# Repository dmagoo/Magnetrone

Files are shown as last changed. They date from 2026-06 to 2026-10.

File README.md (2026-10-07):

# Magnetrone

A motorized MIDI sequencer built around a rotating platter driven by a stepper motor.
Magnets placed on the platter pass over Hall effect sensors to trigger MIDI notes,
turning physical arrangement into musical pattern.

---

## Features

- Rotating platter driven by NEMA17 stepper via GT2 belt drive (11:1)
- 8 analog Hall effect sensors, one per note in the current scale
- MIDI note output on DIN connector
- Teensy Audio Shield output (headphone/line out) with a built-in synth and drum kit
- Voices: Piano, E. Piano, Organ, Synth, Bass, Strings, Brass, Mallets, Reed, Guitar
  and Drums, each with its own wave or harmonics, envelope, note length and filter,
  plus None to mute a layer
- Voice Edit (Aux): live tweaks to a layer's wave, envelope and note length,
  its first 16 harmonics, and its own filter with a filter envelope; Save As keeps them in Custom 1-8 (shared by all
  scenes) or as the current scene's own Scene Voice
- Edit Scale: a Custom scale with one chosen note per track, from Sound
  Defaults or live on the Aux; Save As keeps it in Custom 1-8 (shared by all
  scenes)
- Two magnet layers: a magnet's normal pole plays Layer A, its reversed pole Layer B
  (or both, with Layer B's Mode on Stack, or taking turns by revolution, with
  Layer Turns on Alternate, or each on its own Edit Turns pattern of up to 8
  revolutions),
  each with its own voice, MIDI channel, root note, scale, octave, level, Track
  Shift, Wrap and Low Note (Layer B can follow A's voice, octave, root, scale,
  shift and Low Note one by one, from the menu or the Aux; octave, root and
  scale follow by default)
- Per-layer effects, in a fixed chain: Tone (low-pass Cutoff and Resonance),
  Chorus (Rate, Depth, Mix), Delay (Sync to the beat or Free in ms, up to
  2.4 s, Feedback up to 90%, Mix) and Reverb (Room Size, Damping, Mix). Saved
  in scenes, all off by default; Layer B can follow A's per effect. Tone
  Cutoff, Delay Mix, Delay Feedback and Reverb Mix are also Aux Fns
- Per-layer Track Shift raises the run by scale degrees, with Wrap (the run
  rotates around the arm) or No Wrap (the whole run transposes)
- Per-layer Low Note: Inner or Outer sets which end of the sensor arm plays
  the low end of the run
- Drums play a fixed GM kit (one drum per track, busiest on the outer tracks) on
  MIDI channel 10; Track Shift rotates the kit around the tracks and Low Note
  Outer flips it end to end
- 1 revolution = 1 bar; BPM tracks RPM automatically. Beats/Rev from 1 to 32,
  platter speed from 1 to 120 RPM
- The platter is marked in 16 steps
- Bar start (StartPos): a start mark on the platter, located by calibration or
  re-found later (Auto from one magnet, or Manual by jogging the platter), and
  remembered across power cycles when the platter was at rest
- Front: where the player sits, set first in calibration and Calib. StartPos
  (the magnet is turned to the player, by hand or with the Speed knob, before
  the spin). Tools > Go to Front turns the mark there the shorter way round
- Placement Mode (Tools): Speed jogs the platter (press: Go to Front), Aux snaps
  to the next step or beat, Volume mutes and unmutes single tracks
- Scenes: the whole sound of both layers, 8 saved slots plus a Defaults scene
  edited from the menu; loaded live on the next bar start (or at once, Play
  Setup > Scene Load). Aux changes are live
  only, on top of the current scene. Read-only demo scenes are built into the
  firmware from JSON files (docs/scene-format.md), and a `scenes` serial
  command prints the saved scenes in that format
- Scene Codes (Aux > Scene Codes): a code of up to 14 characters for the
  current sound's main settings (each layer's root, octave, scale, voice,
  shift, Low Note, Wrap and mode, plus Layer Turns and the turn patterns), to enter on another
  table or after a firmware update. Fields at their defaults cost nothing, so
  a code changing only the roots is 3 characters
- [Record Designer](https://dmagoo.github.io/Magnetrone/tools/record-designer/) (`tools/record-designer/`): a
  browser tool to design a "record", a magnet pattern on a step grid plus its
  Scene Code, play it back, save songs and share them as links, and export a
  full-size SVG/PDF template to print or laser cut into a platter cover. Runs
  from the link or straight from disk
- MIDI beat clock driven by platter position, with Song Position Pointer so
  external bars line up with the start mark
- MIDI in (control only): a per-layer input channel; keys drive a MIDI Fn
  (Pitch, Shift, Scale Learn, Set Scale, Fingered or One Finger), the bend wheel bends the table, CC 7 volume,
  CC 20 octave; with Play Setup > MIDI CC on, CCs 74, 71, 93, 94, 12 and 91
  set the effects
- LCD menu: Sound Defaults (both layers), Play Setup, System and Tools
- Speed and volume adjustable live at any time via dedicated encoders; touching
  either one returns to the home screen from any menu (prompts and Scene
  Code entry excepted).
  From a stop, turning Speed starts from zero in the turned direction; a
  press resumes the last speed
- Aux knob changes one bound function live (Pitch, A/B Balance, Layer Turns, Load Scene,
  or a layer's Voice, Root Note, Scale, Octave, Shift, Low Note, Wrap, Mode,
  Tone Cutoff, Delay Mix, Delay Feedback or Reverb Mix); its list also holds
  Save Scene, Scene Codes and Reset All
- Menu knob opens the main menu from the home screen by turning or pressing;
  the Menu button leaves the Aux screens straight back to the home screen, and
  the Aux button leaves the main menu (prompts excepted)
- Welcome tune plays on boot -- previews what Layer A's tracks play, hall 1 to 8
  and back, including its key, octave, Track Shift, Wrap and Low Note; a Menu
  button press skips it
- LCD backlight timeout: configurable from always off to always on
- Stepper motor sleeps when idle to reduce heat and power draw
- Calibration (at 24 RPM, clear platter then one magnet on the start mark)
  measures sensor baselines and noise, threshold, magnet pole, the belt reduction
  (e.g. "Belt 10.9:1", counted in motor steps) and the bar start
- Tools menu: Go to StartPos, Go to Front, Placement Mode, calibration,
  StartPos, Machine Info (RPM, belt ratio, StartPos, threshold, motor driver), live
  Sensor Levels, Sensor Timing, Track Notes and Resources (audio load) screens, Reset Settings (keeps calibration, Front and scenes
  1-8) and Factory Reset
- All settings persisted to EEPROM across power cycles
- Teensy 4.1

---

## Code Summary

The firmware is structured as a set of independent modules: stepper motor control
uses an IntervalTimer ISR for non-blocking step generation; Hall sensor polling
fires each note when the magnet is centered on its sensor, predicted from a
threshold-to-peak angle each sensor learns as it plays (so timing holds on every
track and at any speed), with re-arm and debounce; the sequencer maps sensor
index to scale degree and fires timed MIDI note on/off pairs; the audio module drives
an 8-voice synth bank per magnet layer plus a shared drum kit through the SGTL5000
codec in parallel with MIDI out; the menu
is a simple state machine driven by three encoders with live speed and volume handling
at all times. The platter keeps a signed step count, so the bar phase is exact; MIDI
clock and scene loads are driven from it. A calibration routine samples the sensor
baselines and noise, counts motor steps over one platter revolution, and derives a threshold,
RPM correction factor and bar start stored in EEPROM.

---

## Hardware Summary

The controller is built on a Teensy 4.1 with a Teensy Audio Shield (SGTL5000) for
audio output. A NEMA17 stepper motor drives the platter through a GT2 belt at 11:1
reduction, controlled by a TMC2209 driver (configured over UART) from 24V DC. Eight
ratiometric Hall effect sensors (A1301) are powered at 3.3V and read directly by the
Teensy ADC. A 16x2 I2C LCD with PCF8574T backpack provides the display. MIDI DIN
in/out is present with optoisolation on the input. Power is supplied via 24V barrel
jack through a panel-mount power switch and an MP1584EN buck converter to 5V.

---

## Installation

### Requirements

- PlatformIO (CLI or VS Code extension)
- Teensy 4.1

### Build and Upload

1. Open the `firmware/` directory in VS Code with the PlatformIO extension,
   or use the PlatformIO CLI.

2. Build:

       cd firmware
       pio run -e teensy41

3. Upload:

       pio run -e teensy41 --target upload

### First Run

On first boot, no calibration data is present and the table offers to calibrate
(later: Menu > Tools > Full Calibrate). Clear the platter when asked, then place a
single magnet on the start mark on the outer track. See the
[user guide](docs/user-guide.md) for details.

### Diagnostics

For hardware faults, the firmware has a diagnostics mode used over the USB
serial monitor (`pio device monitor`). Hold the Menu button at power-up, or
type `diag` in the monitor while the table runs. It reports the display, audio
board, motor driver and every sensor every 5 seconds, and takes commands for
running and tuning the motor. Type `help` in the monitor for the commands; see
Troubleshooting > Diagnostics mode in the [user guide](docs/user-guide.md).

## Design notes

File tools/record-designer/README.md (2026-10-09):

# Record Designer

Design a record for Magnetrone: a magnet pattern on a step grid plus the
Scene Code that sets the table up to play it. Exports a full-size template
to laser cut into a platter cover, or to print and place magnets by.

Use it online at https://dmagoo.github.io/Magnetrone/tools/record-designer/, or open `index.html`
in a browser straight from disk (no install, no internet). Work is kept in
the browser's local storage.

Two views, picked at the top right: **Sequence** (grid, playback, scene)
and **Template** (preview and export). The buttons left of them open the
[MIDI](#midi) panel and pick the theme: Auto (follows your system), Light or
Dark.

## Grid

- One row per track, track 1 (inner) at the bottom, track 8 at the top.
  One column per step, step 1 at the left, at the start mark.
- Steps per revolution = Beats/Rev x Subdivisions (default 4 x 4 = 16).
  Changing them keeps every magnet that lands on a step of the new grid.
  Steps are named by beat: 1, 1.2, 1.3, 1.4, 2, ...
- Click an empty slot to place a magnet: A (normal pole, plays Layer A) or
  B (reversed pole, plays Layer B), whichever layer you used last (A at
  first). Click again to flip it to the other layer, again to remove it.
  Clicking a magnet already there flips it, then removes it. Right click
  removes a magnet at once. With the
  colored magnets, A is blue side
  up and B is black side up (the table's calibration sets this; Menu >
  System > Magnet Pole swaps it).
- Block collisions: striped slots would overlap a placed magnet and cannot
  be used; hover one to see which. With it off, overlapping magnets are
  outlined in red. The check uses the larger of the magnet diameter and the
  magnet hole.
- The toolbar counts the magnets placed, in all and per layer.
- Undo and Redo (Ctrl+Z, Ctrl+Y) cover grid edits: slots, Clear and step
  count changes. The history lasts until the page is closed.
- Each magnet shows what it plays with the current scene: a note ("C3"),
  or for drums the letter Track Notes uses (X crash, t low tom, T high tom,
  C clap, O open hat, S snare, K kick, H closed hat). With Stack it shows
  both layers' notes. Each row label shows what an A and a B magnet on
  that track play ("C4/X"), once if they match ("C4"); hovering an empty
  slot shows the same.

## Scene

The Scene Code fields, grouped as Sound (voice, root, octave, scale, each
with a Same as A box for Layer B; Octave, Root and Scale on by default),
Arrangement (shift, Low Note, Wrap, Layer B's Same as A settings) and
Layers (modes, Layer Turns, Edit Turns). Settings that have no effect right now (a Drums
layer's root, a layer that is Off, Layer B on Same as A) are greyed out but
stay editable, since the code still holds them; hover one to see why.
Hover a setting's name (dotted underline) for what it does. Each Shift
option shows what the low track then plays ("1  D4", or "5  Snare" on
Drums); Low Note's options say which track is low (Inner, track 1; Outer,
track 8). Octave is a number box, 0 to 7.

**Scale** includes **Custom**: one note per track, as on the table. The
**Edit Scale** row lists each layer's eight slots as the table's Edit Scale
does ("C+0" is the C in the layer's Octave, "C+1" the one above; slot 1 is
the low track at Shift 0), the Custom notes or, until the layer plays a
Custom scale, its scale's first eight notes. Changing a slot makes the scale
Custom, starting from what it was playing; choosing Custom with none set
does the same. **Reset** puts the layer's Scale and Custom notes back to the
song as saved (the factory scene for a song not saved yet). Layer B following
A's Scale plays A's Custom notes.

The Scene Code does not hold a Custom scale (it reads as Major on the
table), so a Custom scale is kept in the song and its link, not the code.
The Scene panel and the Template view say so whenever a layer plays one, and
the template's labels list its notes, to set on the table with Edit Scale.

**Hear: A / B** (Scene header) plays that layer's tracks 1 to 8 up and
back down in sixteenths, as the table plays its welcome tune at power-up
(the table's tune is Layer A). With **Auto** on, changing a scene setting
plays the changed layer's run, unless the grid is playing.

Beside it, the swap button (two arrows) swaps Layers A and B, and **A→B**
copies Layer A to Layer B, leaving A as it is. Both cover the settings the
two layers share: Voice, Root, Octave, Scale, Shift, Low Note, Wrap and the
turn patterns. Mode, Layer B's Same as A boxes and Layer Turns stay as they
are.

**Edit Turns** shows each layer's turns as the table does: a turn's number
if the layer's magnets are heard on that revolution, - if not, | where the
cycle ends (8 turns without one). Click a turn to change it: on, off, the
end of the cycle (not turn 1), on again. Clicking the | or past it makes the
cycle 8 turns again. Changing a turn sets Layer Turns to Custom, starting
from what it was playing; Together and Alternate keep the Custom patterns.
The turn the position is on is shaded in each layer's strip.

**Reset Scene**, under the settings, sets every scene setting to the factory
values, as with nothing saved (asks first). The grid, BPM and template
settings stay.

The code shows beside Play, with a copy button, and updates as you change
the settings. It is up to 10 characters, or 14 with Layer Turns on Custom or
a voice from E. Piano on. A code can be loaded back. Enter the
code on the table under Aux > Scene Codes > Enter. Beats/Rev is not in the
code; set it on the table under Menu > Play Setup > Beats/Rev.

## Play

Plays the grid at the BPM given, with the table's note mapping (scale
degree, Shift, Wrap, Low Note, Same as A, Stack, Off, Layer Turns, the drum
kit). The RPM that BPM means on the table is shown beside it; BPM is kept
within the table's 1 to 120 RPM at the current Beats/Rev. The sounds are
approximations of the table's voices. Turn 1 of Layer Turns is the first
revolution, and beside BPM the layers heard on the current revolution are
shown ("Turn: A + B") unless Layer Turns is Together.

- Play / Pause (Space). Pause keeps the position; Play goes on from there.
- To start (Home) moves the position back to step 1.
- The arrows button (right of Play) plays backwards, as the table does with
  Speed turned below zero. Playing, it turns round at the current step.
- Click a step number to move the position there. Paused, that column
  plays once; playing, it jumps there.
- Placing a magnet plays its note.
- The shaded band shows the position.

## MIDI

The MIDI button (left of the theme button) opens the MIDI panel. It works in
Chrome and Edge, through the browser's Web MIDI; Safari has none. **Use
MIDI** turns it on (the browser asks for access the first time). The
settings are kept per browser, like the table's Play Setup, not in the song.
The button lights while MIDI is on and blinks when a message comes in.

MIDI In works as the table's MIDI IN (see the user guide's MIDI In section):

- **MIDI In**: All inputs, None, or one port. **A In channel** and **B In
  channel** (default 1 and 2, or Off) are the channels each layer listens on;
  both on one channel apply to both. Layer B on Same as A does not listen.
- **MIDI Fn**: what keys do. Off, Pitch, Set Scale, Fingered, One Finger,
  Shift, Play Along, Scale Learn, as on the table. Changing it releases held
  keys. Fingered, One Finger and Scale Learn write the layer's Custom scale
  (see [Scene](#scene)).
- Scene changes from MIDI (keys, CC 20 Octave) edit the song: the chip shows
  "(edited)", **Save** keeps them and **Revert** drops them, as Save Scene
  keeps them on the table.
- Play Along keys play the layer's voice, velocity counting, as long as
  held. On a drum layer each drum plays on its General MIDI key.
- The bend wheel bends everything up to 2 semitones, notes sounding
  included. **CC 7** sets the volume. With **MIDI CC** on, CCs 74, 71, 93,
  94, 12 and 91 set each layer's Tone Cutoff and Resonance, Chorus Mix,
  Delay Mix and Feedback, and Reverb Mix.

Volume, bend and effects are live only: not saved with the song (the Scene
Code does not hold them either). The panel shows them under **Live, not
saved**, with a button to reset them. They start as the table's factory
settings (volume 50%, effects off; Delay Sync 1/2 beat, Feedback 30%). The
effects are approximations of the table's.

MIDI Out, while the grid plays:

- Each layer's notes on its voice's Auto channel (Piano 1, Bass 2,
  Strings 3, Synth 4, E. Piano 5, Organ 6, Brass 7, Mallets 8, Reed 9,
  Drums 10, Guitar 11), velocity 127, for the voice's note length (drums
  50 ms). A track's next note ends the one before.
- The bend, on the melodic channels in use, each told the bend range first.
- Clock (24 a beat) with Song Position and Continue on Play, and Stop on
  Pause. A jump, turning round or a Beats/Rev change starts the clock over.
- Hear runs, placed magnets and Play Along keys are not sent out.

Not here, as on the table: following an external clock.

## Songs and sharing

The **Songs** strip under the transport keeps saved songs as chips, in
this browser's local storage. On a narrow screen (under 600 px) the chips
wrap onto as many rows as they need, with the buttons below them.

- **Save** keeps your changes in the chip you are on (it is greyed when
  there is nothing to save). A song not saved yet (new, or started from
  Empty) is named first and becomes a chip. Until you save, the chip shows
  "(edited)".
- **Save as new** makes a new chip and leaves the one you are on as it was.
  The name is pre-filled with a copy number, "My tune (2)"; only a
  trailing "(n)" counts up, so "Waltz no. 3" becomes "Waltz no. 3 (2)".
- **Revert** discards your edits and goes back to the saved chip (asks
  first; greyed when there is nothing to revert). Clicking the edited chip
  does the same.
- Click a chip to switch to it. Playing carries on into the new song. If
  the current song has unsaved changes, it asks first.
- Double-click a chip to rename it; x removes it. **Empty** is always
  there: the factory scene on an empty grid.
- The link button beside the Scene Code copies a link holding the whole
  song and its name: grid, scene (Custom scales included), BPM and template
  settings. It asks for a
  name if the song has none, and saves the song as Save does.
- Opening a link adds its song as a chip (or picks the chip it already is),
  so you can always get back to it. It points at this page's address, so
  it opens the song for anyone who has the page there, such as the hosted
  copy; a link to a file on your drive only works on your machine.

## Template

SVG or PDF, full size, on Letter or A4. If printing, print at 100% (actual
size, no fit to page) and check the 100 mm scale bar.

| Color | Lines |
|---|---|
| Red `#FF0000` | Through cut: outline (200 mm) and center hole (14 mm) |
| Green `#00FF00` | Layer A magnet holes (default 11 mm, for 10 mm magnets): cut through or kiss cut |
| Magenta `#FF00FF` | Layer B magnet holes, same size |
| Blue `#0000FF` | Score: track rings, start mark, the A/B mark beside each hole, Scene Code and Beats/Rev, song name |
| Black | Labels and scale bar, below the record. Not part of the record. Template settings **Labels below the record** (default on, kept per browser) leaves them out of the export. |

All lines are hairlines (0.001 in). The start mark is at the top.

- Track rings are broken around every hole, with a gap 1 mm wider than the
  hole, so they never cross one. A ring with no holes is a whole circle.
- The A/B mark sits just after its hole, in step order; just before it if a
  magnet is packed right after; left off if magnets are packed on both
  sides.
- The Scene Code and Beats/Rev ("J  4 BEATS/REV") are 5 mm tall along a
  track ring, centered in the longest stretch with no magnets, outer tracks
  first; the ring is broken under them. Without room at 5 mm they are 3 mm;
  without room at 3 mm they fall back to 1.5 mm along the outer edge, and
  the Template view says so. Leaving a few steps in a row free on one track
  (outer tracks need the fewest) keeps them readable.
- **Platter marks** (Template settings: Off, 10, 12 or 16, default 16): 5 mm ticks
  across every ring, evenly spaced from the start mark, like the marks on a
  platter cover, so the template can be used as a guide on a marked cover
  without cutting it. They are the cover's, not the song's: they ignore
  Beats/Rev and the steps, are kept per browser, and are not in the song
  or its link. A tick near a hole (or its A/B mark) or across text on its
  ring is left out.
- A saved song's name is scored the same way, after the code, in the
  longest stretch left clear of magnets and the code. Without room on a
  ring it takes the outer edge, unless the code is already there; then it
  is left off the record. The Template view says so either way. It is also
  the first label below the record, when labels are on. Letters the template font lacks are
  dropped.

- A layer playing a Custom scale gets a label line with its Edit Scale
  notes ("A EDIT SCALE (NOT IN CODE): 1:C+0 2:D+0 ..."), since the code
  does not hold them. With labels off they are not on the export, and the
  Template view says so.

Lay the template on the platter with the center hole on the spindle and
the start mark on the platter's start mark.

## Platter direction

- **Platter forward, seen from above** (Template settings): Clockwise,
  confirmed on the table 2026-10-04. Steps run around the template in the
  order they pass the sensor arm, so this must match the table or the
  record plays backwards.

## Sources

- Track radii and magnet diameter: `firmware/include/config.h`
  (`TRACK_RADIUS_MM`, `MAGNET_DIAMETER_MM`), which match the platter CAD.
- Outline and center hole: `hardware/cad/platter/dxf/Platter - Disc.dxf`.
- Scene Code: a port of `firmware/src/sequencer/scene_code.cpp`.
- MIDI: `firmware/src/midi/midi_in.cpp`, `midi.cpp`, `transport.cpp`;
  effects: `audio/audio.cpp`, `config/storage.cpp` (factory effects).
- Note mapping: `firmware/src/sequencer/layers.cpp`, `sequencer.cpp`,
  `scale.cpp`, `audio/kit.h`, `audio/voice.cpp`.

If any of these change in the firmware, change them here too.

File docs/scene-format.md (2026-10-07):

# Scene Format

A scene written as JSON. It is the source format for the demo scenes built into
the firmware (the demos at the end of the **Load Scene** list), and what the table prints when it dumps
its saved scenes over USB serial. It is meant for whoever makes demos, and is
the implementation guide for the feature, not for playing the table: see the
[User Guide](user-guide.md) for that.

To share a sound by hand instead, without a computer, use a Scene Code (see
[Scene Codes](user-guide.md#scene-codes) in the User Guide). A code holds only
each layer's main settings, not effects, levels or custom voices.

## Rules

- **Leave out what you did not change.** Any field left out takes its factory
  value, the same one Factory Reset gives. So a demo lists only what makes it
  different, and if the factory values change, demos that leave a field out
  follow. This applies everywhere, harmonics included. The scene that is loaded
  is always complete.
- **Names, not numbers.** Settings such as voice, scale or root are written by
  name. Names are not case sensitive; this document writes them in lowerCamel
  (`drums`, `off`, `pentatonicMinor`). An unknown name fails the build.
- **Keys are lowerCamel** (`lowNote`, `shiftSameAsA`).
- **The dump leaves out factory values** for you, so a dumped scene already
  holds only its changes. Prune further by hand.
- **Demos must not use Custom 1 to 8.** Those are edited by the player, so a
  demo would change under them. Use a scene voice (`sceneVoice`) instead, or
  for a scale, the layer's own `custom`.

## Scene

| Key | Value |
|-----|---|
| `name` | The scene's name. |
| `pitch` | Pitch offset in semitones; fractions allowed. Factory 0. |
| `balance` | A/B Balance, -10 (all A) to 10 (all B). Factory 0. |
| `layerA`, `layerB` | The two layers, below. |
| `customVoices` | Dump only, printed on its own after the scenes: Custom 1 to 8 (`custom1` ... `custom8`), each a voice as below. They are shared by every scene, not part of one, so a demo cannot have this. |
| `customScales` | Dump only, like `customVoices`: the saved Custom scales 1 to 8 (`custom1` ... `custom8`), each a list of steps as `custom` below. |

## Layer

| Key | Value |
|-----|---|
| `mode` | `on`, `off`. Layer B also: `sameAsA`, `stack`. |
| `voice` | `piano`, `ePiano`, `organ`, `synth`, `bass`, `strings`, `brass`, `mallets`, `reed`, `guitar`, `drums`, `none`, `custom1` to `custom8`, or `sceneVoice`. (`synth` was `leads` before 2026-10-06.) |
| `sceneVoice` | The layer's own voice, a voice as below. Used when `voice` is `sceneVoice`. |
| `channel` | `auto` (follows the voice), or a MIDI channel 1 to 16. |
| `root` | `c`, `c#`, `d`, `d#`, `e`, `f`, `f#`, `g`, `g#`, `a`, `a#`, `b`. |
| `scale` | `major`, `minor`, `pentatonicMajor`, `pentatonicMinor`, `blues`, `chromatic`, `dorian`, `mixolydian`, `learned`, `custom`. |
| `learned` | The Learned scale: semitones above the root, 0 to 11. Empty if none (then `learned` plays as major). |
| `custom` | The Custom scale (Edit Scale): one note per track, slot 1 first, as 8 steps in semitones from the root, -12 to 35 (12 is the octave above). Left out if none (then `custom` plays as major). |
| `octave` | 0 to 7. |
| `level` | 0 to 100 (percent). |
| `shift` | Track Shift, 0 to 7. |
| `wrap` | `true` or `false`. |
| `shiftSameAsA` | Layer B only: play A's Shift and Wrap. |
| `lowNote` | `inner` or `outer`. |
| `lowNoteSameAsA` | Layer B only: play A's Low Note. |
| `rootSameAsA` | Layer B only: play A's Root. Factory `true`, so a Layer B that sets its own `root` also sets this `false`. |
| `scaleSameAsA` | Layer B only: play A's Scale (with A's `learned` and `custom`). Factory `true`, as `rootSameAsA`. |
| `voiceSameAsA` | Layer B only: play A's Voice. Factory `false`. |
| `octaveSameAsA` | Layer B only: play A's Octave. Factory `true`, so a Layer B that sets its own `octave` also sets this `false`. |
| `turns` | Layer B only: Layer Turns, `together`, `alternate` or `custom`. |
| `turnPattern` | The layer's turns (Edit Turns), played while Layer B's `turns` is `custom`: as the table shows them, turn n's number if the layer plays it, `-` if not, then `\|` where the cycle ends if it is shorter than 8, such as `"1-3-5-7-"` or `"1--\|"`. Factory `"12345678"`. |
| `tone`, `chorus`, `delay`, `reverb` | The layer's effects, below. |

## Effects

Percentages run 0 to 100. On Layer B, each effect also takes `sameAsA`
(`true` plays A's settings for that effect).

| Effect | Keys |
|---|---|
| `tone` | `cutoff` (`off` = 100), `resonance`. |
| `chorus` | `rate`, `depth`, `mix` (`off` = 0). |
| `delay` | `mode` (`sync` or `free`), `sync` (`1`, `1/2`, `3/8`, `1/3`, `1/4`, `1/5`, `1/6`, `3/16`, `1/8`, `1/10`, `1/12`, `1/16`, `1/32` of a beat), `time` (free time, 10 to 2400 ms), `feedback` (0 to 90), `mix` (`off` = 0). |
| `reverb` | `roomSize`, `damping`, `mix` (`off` = 0). |

## Voice

Used by `sceneVoice` and `customVoices`.

| Key | Value |
|-----|---|
| `base` | The built-in voice it was made from (any `voice` name above but `none`, and not a custom or scene voice); sets the Auto MIDI channel and every field left out. |
| `wave` | `sine`, `triangle`, `saw`, `square`. |
| `harmonics` | Up to 16 levels, 0 to 100, from the fundamental up. Present means the voice plays these instead of the stock wave. Left out, it plays what `base` plays: its harmonics if it has them (most built-ins do), else its wave, or `wave` if given. A shorter list takes the rest from the stock wave (of `wave`, or of `base`). |
| `attack`, `decay`, `release` | Milliseconds. |
| `sustain` | 0 to 100 (percent). |
| `length` | Note length, milliseconds. |
| `filter` | The voice filter: `cutoff` (`off` = 100), `resonance`, `amount`, `attack`, `decay`, `release` (milliseconds), `sustain` (percent). |

## Dumping scenes from the table

1. Save the scene you dialed in to a slot (**Aux > Save Scene**).
2. Switch the table off and unplug the 24V supply. Never connect USB while
   the 24V supply is plugged in.
3. Connect USB and open a serial monitor.
4. Type `scenes`. The table prints Defaults and every used scene 1 to 8, each
   under a `--- Scene 3 ---` line, then the used Custom voices, as JSON. It
   leaves out fields that match the factory values, and in a voice, those that
   match its `base`.
5. Copy the scene you want, from `{` to `}`, into a demo file (below). Set its
   `name` and prune it by hand. A scene playing a Custom voice has to be
   changed to a `sceneVoice` first (copy the voice from the Custom voices).

## Adding a demo

1. Add a file to `firmware/demos/`, one demo per file. The file name sets the
   of the demos in **Load Scene**, so start it with a number:
   `01-drift.json`, `02-undertow.json`.
2. Set `name`: that is what the Load Scene list shows.
3. Build. A script runs before every build, checks each demo and turns them
   into firmware data. A bad file (unknown key or name, value out of range,
   a Custom voice) fails the build with the file and the field. To check the
   files without building, run `python tools/build_demos.py` in `firmware/`.
4. Flash, and load it from **Aux > Load Scene**: the demos follow scene 8, as
   `Demo1: Drift` (the name cut to fit the display).

## Implementation

- **Dump:** the `scenes` serial command in normal mode
  (`src/sequencer/scene_dump.cpp`, called from the serial poll that also
  listens for `diag`). It compares against `storageFactoryScene()` and, for a
  voice, `storageStockVoice(base)`.
- **Build:** `tools/build_demos.py`, run by PlatformIO before each build
  (`extra_scripts = pre:...`). It reads `demos/*.json` in file name order,
  validates them, and writes `src/sequencer/demos_data.h` (generated, not in
  git). Names are matched case insensitively.
- **Factory fill:** the generated data holds only the fields each demo sets.
  The firmware builds a demo by starting from `storageFactoryScene()` and
  applying them (`src/sequencer/demos.cpp`), so a change to the factory values
  reaches every demo that leaves that field out.
- **Storage:** demos live in flash, read-only, and take none of the 8 slots.
  Their scene ids follow the slots (Demo 1 is id 9). The current scene id is
  saved as for a slot, so a demo loads again at power-up; if a later build has
  fewer demos, Defaults loads instead. Adding or reordering demo files shifts
  which demo an id names.
- **Menu:** the demos follow scene 8 in the **Load Scene** list and load like
  any scene, at the next bar. The home screen shows `Demo 1`. The `*` mark and
  Aux **Reset All** compare against the demo.
- **Scene voices:** every scene load, saved or demo, copies the scene's own
  voices into the live sound, and a layer set to Scene Voice plays that copy.
- **Saving:** **Save Scene** to a slot saves a loaded demo like any scene, its
  voices included. **Voice Edit > Save As** offers no Scene Voice in a demo,
  as in Defaults: save the scene to a slot first.

## Example

The factory Defaults scene with every field written out, except that Layer A
plays Piano as a scene voice, plus a Custom 1 as a dump would show it. A demo
would leave out everything here that matches the factory values.

```json
{
  "name": "defaults",
  "pitch": 0.0,
  "balance": 0,
  "layerA": {
    "mode": "on",
    "voice": "sceneVoice",
    "sceneVoice": {
      "base": "piano",
      "wave": "triangle",
      "attack": 5,
      "decay": 400,
      "sustain": 20,
      "release": 400,
      "length": 250,
      "filter": {
        "cutoff": "off",
        "resonance": 0,
        "amount": 0,
        "attack": 5,
        "decay": 300,
        "sustain": 50,
        "release": 300
      }
    },
    "channel": "auto",
    "root": "c",
    "scale": "major",
    "learned": [],
    "octave": 4,
    "level": 100,
    "shift": 0,
    "wrap": false,
    "lowNote": "inner",
    "tone":   { "cutoff": "off", "resonance": 0 },
    "chorus": { "rate": 30, "depth": 50, "mix": "off" },
    "delay":  { "mode": "sync", "sync": "1/2", "time": 300, "feedback": 30, "mix": "off" },
    "reverb": { "roomSize": 50, "damping": 50, "mix": "off" }
  },
  "layerB": {
    "mode": "on",
    "voice": "drums",
    "channel": "auto",
    "voiceSameAsA": false,
    "octaveSameAsA": true,
    "rootSameAsA": true,
    "root": "c",
    "scaleSameAsA": true,
    "scale": "major",
    "learned": [],
    "octave": 3,
    "level": 100,
    "shift": 0,
    "wrap": false,
    "shiftSameAsA": false,
    "lowNote": "inner",
    "lowNoteSameAsA": false,
    "turns": "together",
    "tone":   { "sameAsA": false, "cutoff": "off", "resonance": 0 },
    "chorus": { "sameAsA": false, "rate": 30, "depth": 50, "mix": "off" },
    "delay":  { "sameAsA": false, "mode": "sync", "sync": "1/2", "time": 300, "feedback": 30, "mix": "off" },
    "reverb": { "sameAsA": false, "roomSize": 50, "damping": 50, "mix": "off" }
  },
  "customVoices": {
    "custom1": {
      "base": "strings",
      "wave": "saw",
      "harmonics": [100, 50, 33, 25, 20, 17, 14, 12, 11, 10, 9, 8, 8, 7, 7, 6],
      "attack": 150,
      "decay": 100,
      "sustain": 80,
      "release": 600,
      "length": 800,
      "filter": {
        "cutoff": 60,
        "resonance": 20,
        "amount": 40,
        "attack": 10,
        "decay": 300,
        "sustain": 50,
        "release": 300
      }
    }
  }
}
```

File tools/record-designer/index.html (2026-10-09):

# Magnetrone Record Designer

## MIDI

Use MIDI (Chrome or Edge)

MIDI In MIDI Out A In channel B In channel MIDI Fn MIDI CC

In: keys drive the MIDI Fn, the bend wheel bends, CC 7 sets the volume and CC 20 the octave. Scene changes edit the song (Save keeps them). Out: each layer's notes on its voice's Auto channel, the bend, and clock with Start and Stop while the grid plays.

### Live, not saved

Reset volume, bend and effects

BPM

Scene Code

Songs:

Save Save as new Revert

Beats/Rev x Subdivisions

Block collisions

Clear

Click an empty slot to place a magnet on the layer you used last (A, normal pole, or B, reversed pole); click again to flip it, again to remove it. Track 1, the inner track, is the bottom row. Step 1 is the start mark. Striped slots would overlap a placed magnet.

## Scene

Hear: A B Auto

A→B

Load

### Sound

### Arrangement

### Layers

Reset Scene

## Template

A 200 mm record, full size, for laser cutting or printing.

No track has room for a readable Scene Code, so it is only 1.5 mm tall at the edge. Leave a few steps in a row free on one track (outer tracks need the fewest).

Paper Magnet hole (mm) Platter forward, seen from above Check this on the table: steps are placed in the order they pass the sensor arm. Platter marks Ticks across every ring, evenly spaced from the start mark, as on a platter cover. They ignore the song's steps. Labels below the record The black text and 100 mm bar. Off, the export has only the record's lines.

Export PDF Export SVG

If printing, print at 100% (actual size, not fit to page) and check the 100 mm bar.

### Line colors

- Cut: outline and center hole
- Layer A magnet holes
- Layer B magnet holes
- Score: rings, start mark, marks, code
- Labels, not part of the record (optional)

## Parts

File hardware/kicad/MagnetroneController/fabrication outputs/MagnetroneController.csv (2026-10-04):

Reference | Qty | Value | DNP | Exclude from BOM | Exclude from Board | Footprint | Datasheet
C1,C2 | 2 | 100uf |  |  |  | Capacitor_THT:CP_Radial_D8.0mm_P3.80mm | ~
C9 | 1 | .1uf |  |  |  | Capacitor_SMD:C_0805_2012Metric_Pad1.18x1.45mm_HandSolder | ~
D1 | 1 | D |  |  |  | Diode_SMD:D_SOD-123 | ~
D2 | 1 | SS34 |  |  |  | Diode_SMD:D_SMA | https://www.vishay.com/docs/88751/ss32.pdf
F1 | 1 | Polyfuse |  |  |  | Fuse:Fuse_Bourns_MF-RHT300 | ~
H1,H2,H3,H4 | 4 | MountingHole_Pad |  | Excluded from BOM |  | MountingHole:MountingHole_3.2mm_M3_ISO7380_Pad_TopBottom | ~
J1 | 1 | Conn_01x04 |  |  |  | Connector_PinHeader_2.54mm:PinHeader_1x04_P2.54mm_Vertical | ~
J2,J3 | 2 | DIN-5_180degree |  |  |  | music-table-footprints:MIDI_Wire_245 | http://www.mouser.com/ds/2/18/40_c091_abd_e-75918.pdf
J4 | 1 | Barrel_Jack_MountingPin |  |  |  | Connector_BarrelJack:BarrelJack_CUI_PJ-102AH_Horizontal | ~
J7 | 1 | Conn_02x05_Odd_Even |  |  |  | Connector_IDC:IDC-Header_2x05_P2.54mm_Vertical | ~
J8 | 1 | Conn_02x13_Counter_Clockwise |  |  |  | Connector_IDC:IDC-Header_2x13_P2.54mm_Vertical | ~
R1 | 1 | 10 |  |  |  | Resistor_SMD:R_0805_2012Metric_Pad1.20x1.40mm_HandSolder | ~
R2 | 1 | 33 |  |  |  | Resistor_SMD:R_0805_2012Metric_Pad1.20x1.40mm_HandSolder | ~
R3 | 1 | 220 |  |  |  | Resistor_SMD:R_0805_2012Metric_Pad1.20x1.40mm_HandSolder | ~
R4 | 1 | 470 |  |  |  | Resistor_SMD:R_0805_2012Metric_Pad1.20x1.40mm_HandSolder | ~
R5 | 1 | 1k |  |  |  | Resistor_SMD:R_0805_2012Metric_Pad1.20x1.40mm_HandSolder | ~
SW9 | 1 | SW_SPST 24V |  |  |  | Connector_JST:JST_XH_B2B-XH-AM_1x02_P2.50mm_Vertical | ~
U1 | 1 | TMC2209_BTT_V1.3 |  |  |  | magnetrone:TMC2209_BTT_V1.3 | https://global.bttwiki.com/TMC2209.html
U9 | 1 | ~ |  |  |  | MP1584EN:SRT_MPT1584EN_Module
U10 | 1 | Teensy4.1 |  |  |  | magnetrone:Teensy41_AudioShield_RevD
U12 | 1 | 6N137 |  |  |  | Package_DIP:DIP-8_W7.62mm | https://docs.broadcom.com/docs/AV02-0940EN

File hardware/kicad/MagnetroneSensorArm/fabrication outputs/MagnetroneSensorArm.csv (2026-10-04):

Reference | Qty | Value | DNP | Exclude from BOM | Exclude from Board | Footprint | Datasheet
C1,C2,C3,C4,C5,C6,C7,C8 | 8 | .1uf |  |  |  | Capacitor_SMD:C_0805_2012Metric_Pad1.18x1.45mm_HandSolder | ~
H1 | 1 | MountingHole_Pad |  | Excluded from BOM |  | MountingHole:MountingHole_3.2mm_M3_ISO7380_Pad_TopBottom | ~
J1 | 1 | Conn_02x05_Odd_Even |  |  |  | Connector_IDC:IDC-Header_2x05_P2.54mm_Vertical | ~
R1,R3,R5,R7,R9,R11,R13,R15 | 8 | 15k |  |  |  | Resistor_SMD:R_0805_2012Metric_Pad1.20x1.40mm_HandSolder | ~
R2,R4,R6,R8,R10,R12,R14,R16 | 8 | 7.5k |  |  |  | Resistor_SMD:R_0805_2012Metric_Pad1.20x1.40mm_HandSolder | ~
U1,U2,U3,U4,U5,U6,U7,U8 | 8 | A1301KLHLT-T |  |  |  | Package_TO_SOT_SMD:SOT-23W | http://www.allegromicro.com/~/media/Files/Datasheets/A1301-2-Datasheet.ashx

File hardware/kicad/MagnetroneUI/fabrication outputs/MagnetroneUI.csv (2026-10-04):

Reference | Qty | Value | DNP | Exclude from BOM | Exclude from Board | Footprint | Datasheet
H1,H2,H3,H4 | 4 | MountingHole_Pad |  | Excluded from BOM |  | MountingHole:MountingHole_3.2mm_M3_ISO7380_Pad_TopBottom | ~
J1 | 1 | Conn_01x04 |  |  |  | Connector_PinHeader_2.54mm:PinHeader_1x04_P2.54mm_Vertical | ~
J2 | 1 | Conn_02x13_Counter_Clockwise |  |  |  | Connector_IDC:IDC-Header_2x13_P2.54mm_Horizontal | ~
Q1,Q2 | 2 | BSS138 |  |  |  | Package_TO_SOT_SMD:SOT-23 | https://www.onsemi.com/pub/Collateral/BSS138-D.PDF
R1,R2,R3,R4,R5,R6,R7,R8,R11,R13 | 10 | 10k |  |  |  | Resistor_SMD:R_0805_2012Metric_Pad1.20x1.40mm_HandSolder | ~
R12,R14 | 2 | 10k | DNP |  |  | "Resistor_SMD:R_0805_2012Metric_Pad1.20x1.40mm_HandSolder" | ~
SW1 | 1 | SW_Push |  |  |  | TerminalBlock_Phoenix:TerminalBlock_Phoenix_MKDS-1,5-2_1x02_P5.00mm_Horizontal | ~
SW2,SW3,SW4,SW5 | 4 | RotaryEncoder_Switch_MP |  |  |  | Rotary_Encoder:RotaryEncoder_Alps_EC11E-Switch_Vertical_H20mm | ~

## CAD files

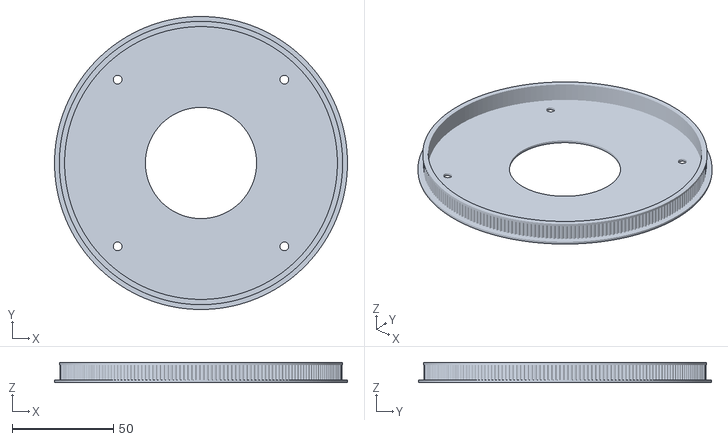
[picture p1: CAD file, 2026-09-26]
hardware/cad/base/stl/Gear Mount - PulleyMount.stl
145.0 x 145.0 x 10.0

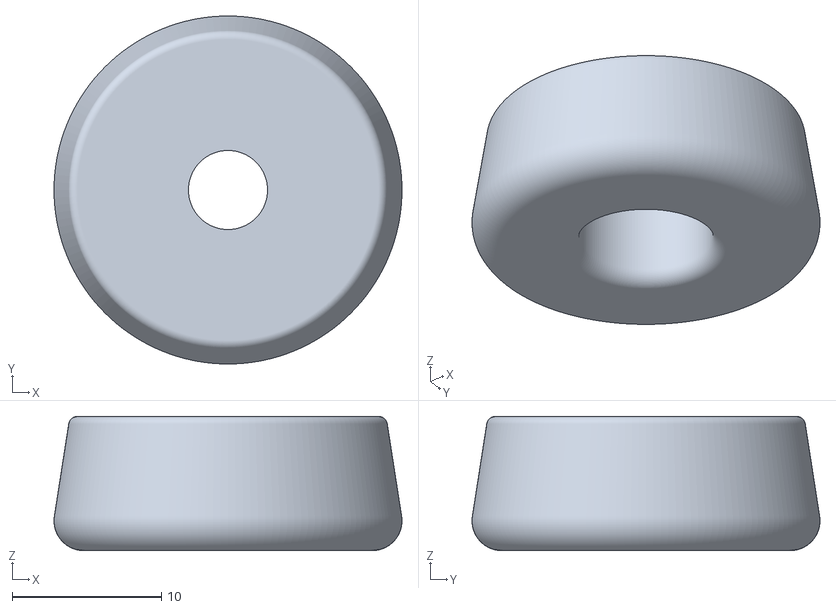
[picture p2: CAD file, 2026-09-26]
hardware/cad/frame/stl/Frame - M5 Foot.stl
23.3 x 23.3 x 9.00

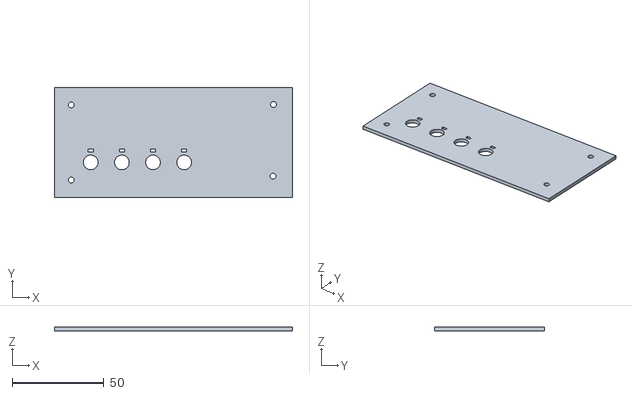
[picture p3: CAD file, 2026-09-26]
hardware/cad/panels/stl/UI Panel - Encoder Panel.stl
130.0 x 60.0 x 2.00

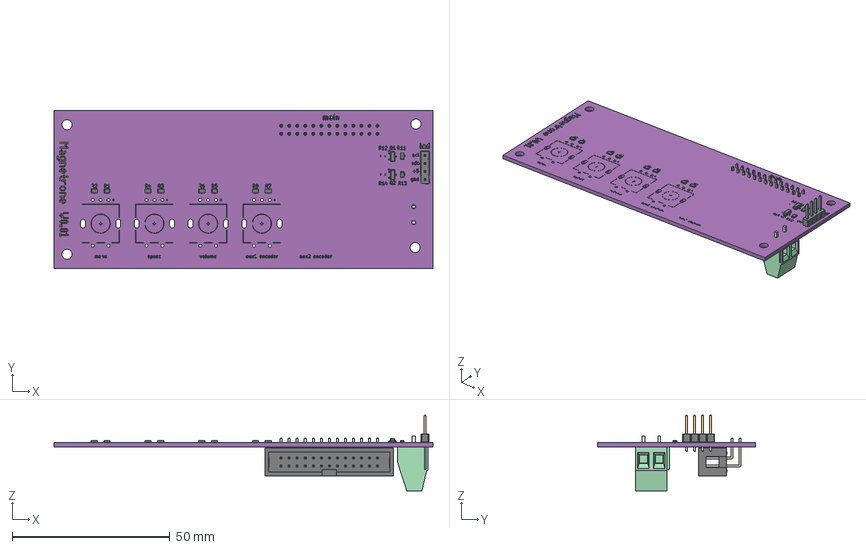
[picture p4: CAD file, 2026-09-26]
hardware/cad/pcb/MagnetroneUI.step
120.0 x 50.0 x 24.0 mm
R_0805_2012Metric x 10
SOT-23 x 2
PinHeader_1x04_P2.54mm_Vertical
IDC-Header_2x13_P2.54mm_Horizontal
TerminalBlock_Phoenix_MKDS-1,5-2_1x02_P5.00mm_Horizontal
MagnetroneUI_silkscreen
MagnetroneUI_PCB

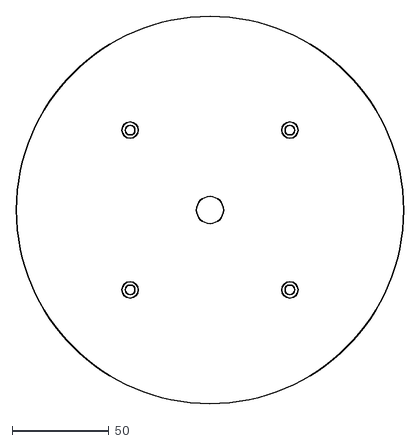
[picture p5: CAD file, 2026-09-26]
hardware/cad/platter/dxf/Platter - Disc.dxf
200.0 x 200.0

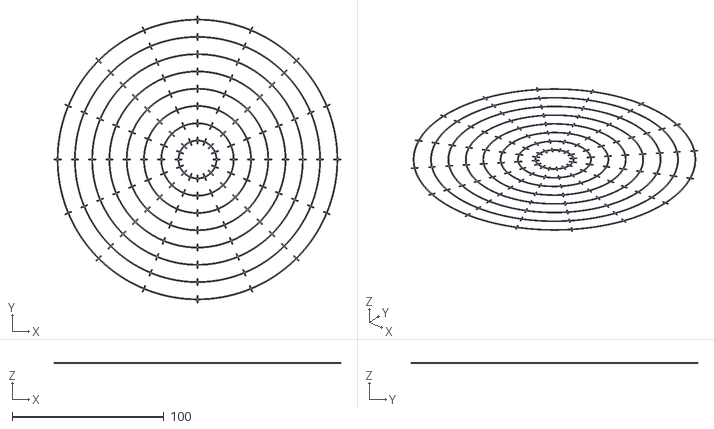
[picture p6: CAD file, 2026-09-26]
hardware/cad/platter/stl/Music Table - Platter - Cover - NEGATIVE LINES.stl
189.4 x 189.4 x 0.2

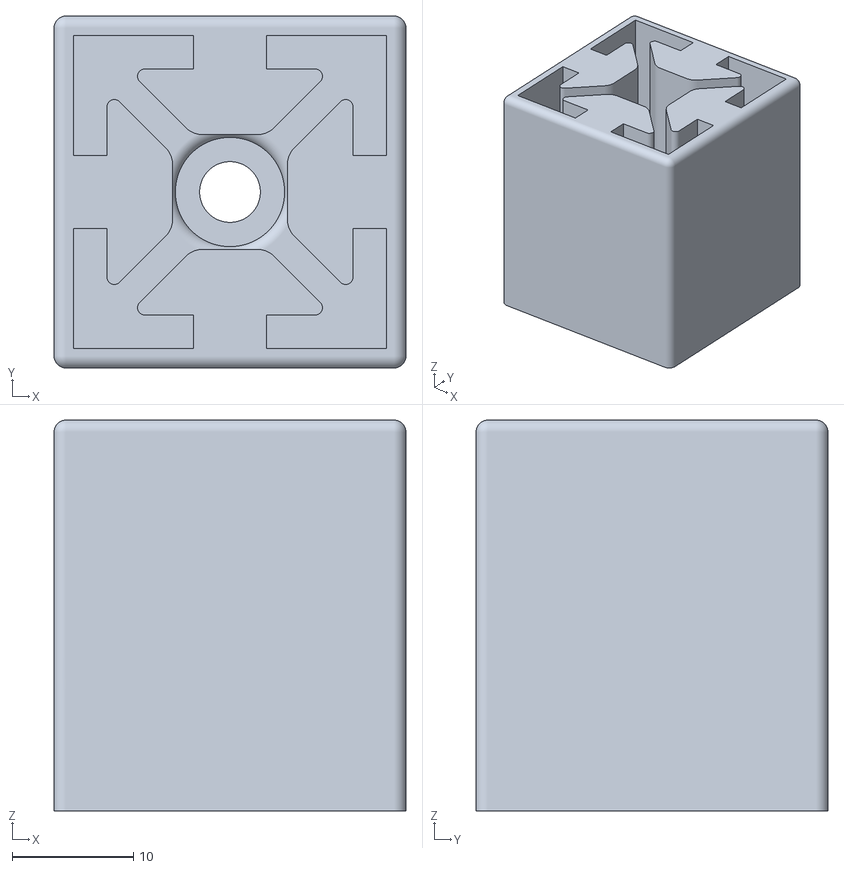
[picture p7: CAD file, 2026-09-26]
hardware/cad/sensor arm/stl/Sensor Arm - SwivelCap.stl
29.0 x 29.0 x 32.2

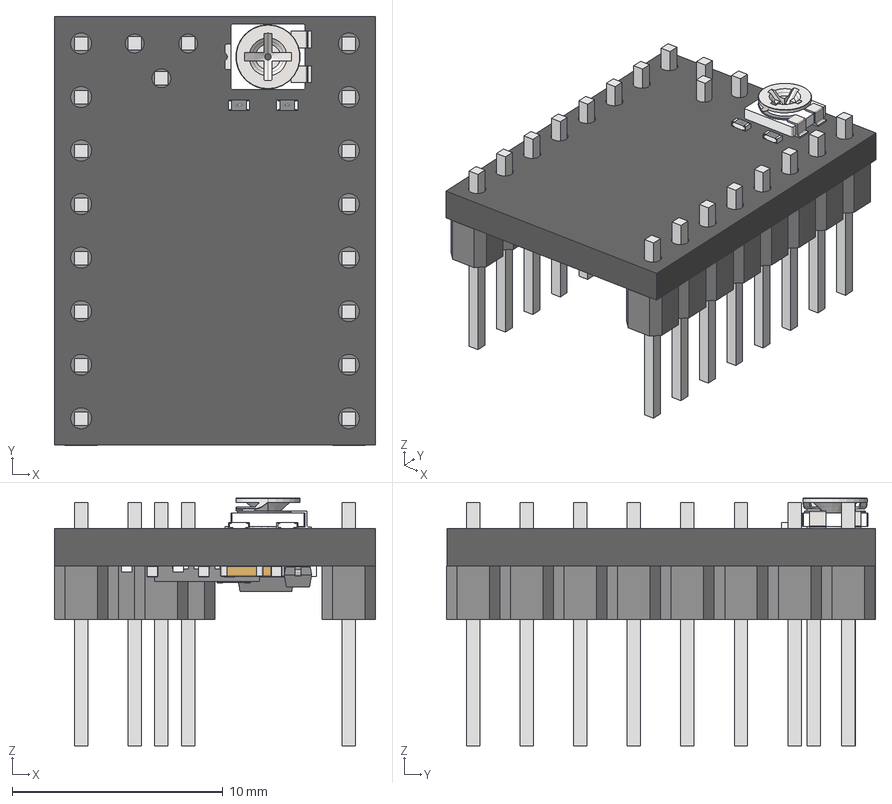
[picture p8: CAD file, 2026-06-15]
hardware/kicad/shared/3dmodels/TMC2209_V1.3.step
15.2 x 20.4 x 11.8 mm
R_0402 x 7
LOGO? x 20
QFN28-5X5_呿极
QFN40_竘褐 x 64
LOGO?0.25
3303W
R_0805 x 2
R_0603
SOD-323
LOGOﾔｲ｣ｭ｣ｰ.｣ｳ x 2
SOD-123
C_0603
C_0402 x 6
C_0805 x 2

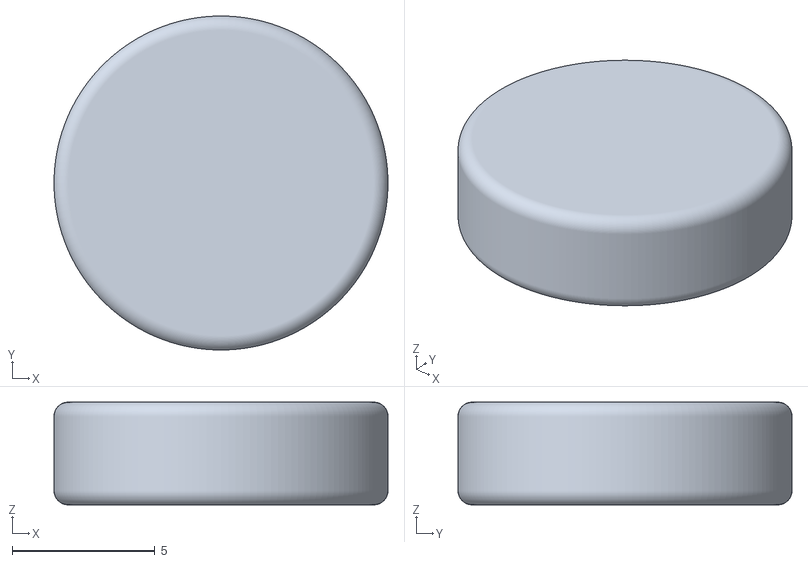
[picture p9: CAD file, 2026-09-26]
hardware/cad/accessories/stl/Magnet Shell - 2.7mmx10mm-print-in-place - 10mmx2.7.stl
11.7 x 11.7 x 3.60

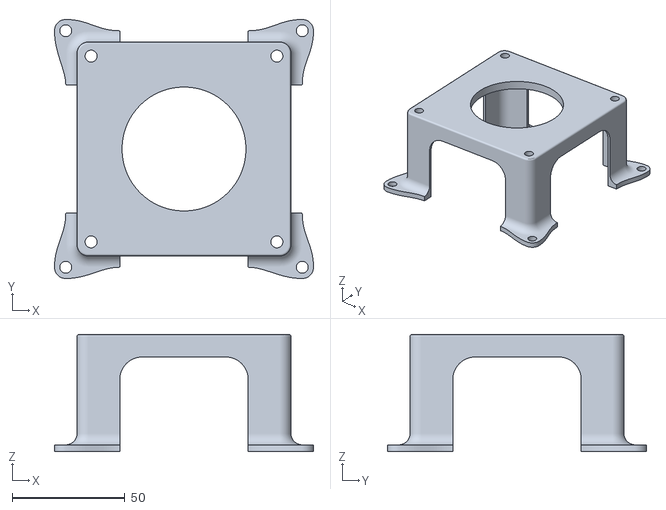
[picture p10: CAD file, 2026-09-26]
hardware/cad/base/stl/Base Unit - LazySusanMount.stl
115.0 x 115.0 x 52.0

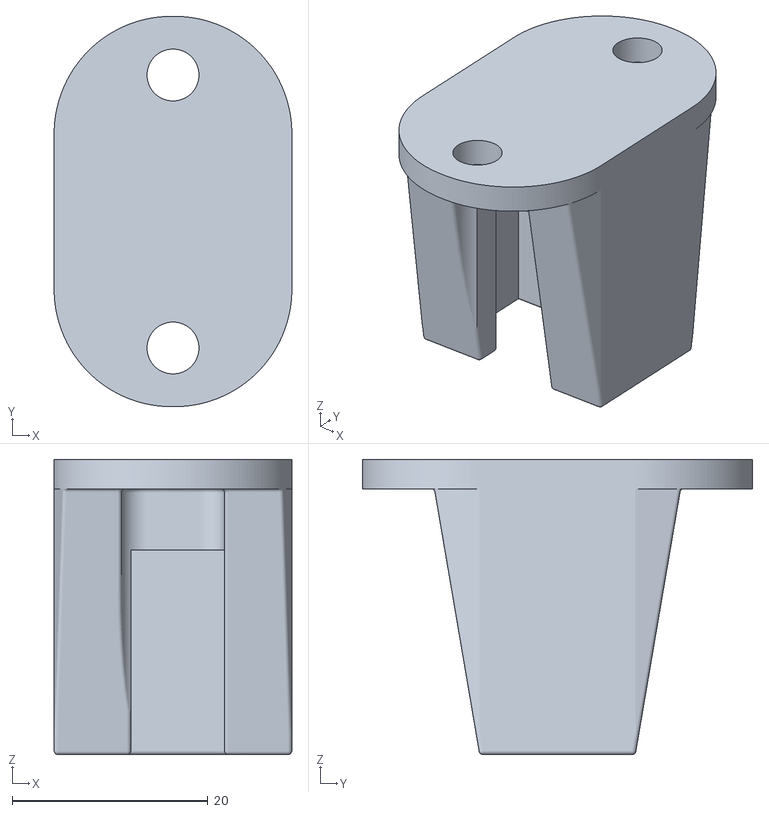
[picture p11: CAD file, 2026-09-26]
hardware/cad/frame/stl/M5 Sensor Bracket.stl
24.3 x 39.9 x 30.2

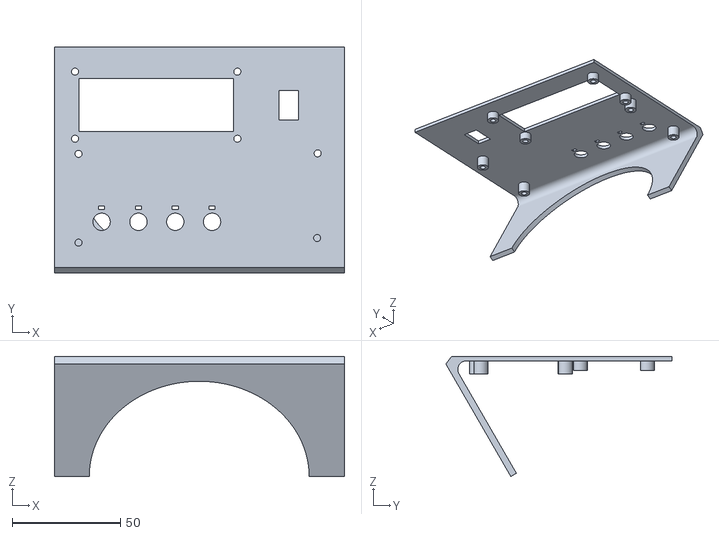
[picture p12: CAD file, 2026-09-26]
hardware/cad/panels/stl/UI Panel - Encoder Panel Stand.stl
134.0 x 104.5 x 55.5

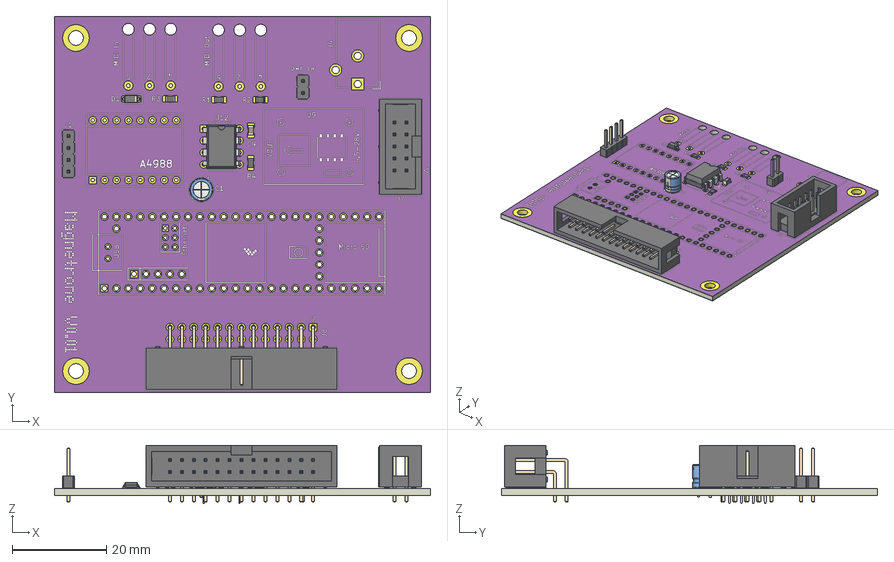
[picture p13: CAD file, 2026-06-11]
hardware/cad/pcb/MagnetroneController.step
80.0 x 80.0 x 12.4 mm
PinHeader_1x04_P2.54mm_Vertical
PinHeader_1x02_P2.54mm_Vertical
C_0805_2012Metric
CP_Radial_D5.0mm_P2.50mm
R_0805_2012Metric x 4
IDC-Header_2x13_P2.54mm_Horizontal
D_SOD-123
IDC-Header_2x05_P2.54mm_Vertical
DIP-8_W7.62mm
MagnetronController_copper
MagnetronController_silkscreen
MagnetronController_soldermask
MagnetronController_PCB

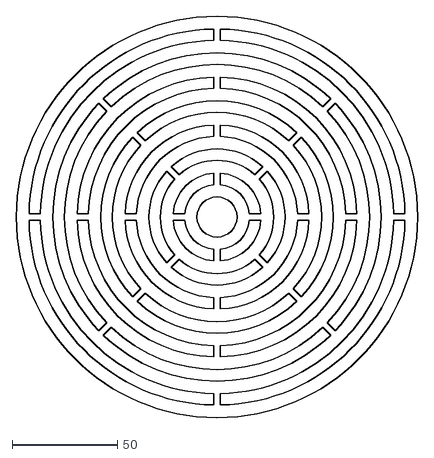
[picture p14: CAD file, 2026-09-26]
hardware/cad/platter/dxf/Platter - SteelRings.dxf
190.6 x 190.6

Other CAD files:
hardware/cad/platter/stl/Platter Cover - Rings - CUT ONE LAYER.stl
hardware/cad/sensor arm/stl/Sensor Arm - lid.stl
hardware/cad/base/stl/Motor Mount - Bracket5mm.stl
hardware/cad/panels/stl/Back Panel - Back Panel Stand.stl
hardware/cad/accessories/stl/t-nut-2020-m5-tread.3mf
hardware/cad/base/stl/Gear Mount - Spacer Jig.stl
hardware/cad/base/stl/Motor Spacer - Spacer Plate-v2.stl
hardware/cad/pcb/MagnetroneSensorArm.step
hardware/cad/platter/stl/Music Table - Platter - Cover.stl
hardware/cad/platter/stl/Platter Cover - Rings.stl
hardware/cad/sensor arm/stl/Sensor Arm - arm.stl

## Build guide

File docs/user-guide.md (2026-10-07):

# Magnetrone User Guide

## What It Is

The Magnetrone is a spinning sequencer. You place magnets on a rotating platter,
and each magnet plays a note as it passes over a sensor arm. One revolution is
one bar, so the pattern on the platter is the pattern you hear.

The platter has eight concentric tracks, one sensor each. By default the
innermost track plays the lowest note of the current scale and the outermost
plays the highest.

The platter is marked in 16 equal divisions. Each one is a **step**, so one
revolution is 16 steps.

Sound comes from the built-in synth (headphone or line out) and from MIDI OUT,
so it can also drive external synths and send them tempo. See [MIDI](#midi).

The **home screen** is where you play. It is a live display of the tempo, the
current scene, the key and the volume, and every menu leads back to it.

## Controls

| Knob | Turn | Press |
|---|---|---|
| Menu | Opens the main menu, then scrolls | Opens the main menu, then selects. On the Aux screens, returns to the home screen |
| Speed  | Platter speed. Below zero it reverses. From a stop it starts from zero, in the direction you turn | Start or stop the platter (start resumes the last speed) |
| Volume | Volume | Mute |
| Aux | Changes the selected function live | Opens the Aux function list. In the main menu, returns to the home screen |

Speed and Volume work from any screen, and touching either one returns to the
home screen. Menus also return to the home screen after a while untouched
(Menu Timeout, 30 seconds by default). Calibration and reset questions are the
exception: they stay on screen until answered. So does entering a Scene Code,
so a code half entered is not lost.

In this guide, **Menu >** paths start at the main menu and **Aux >** paths
start at the Aux function list.

The home screen shows:

```
BPM:120 Scene 2*
C  Major  [███ ]
```

The top line is the tempo (negative means the platter runs in reverse) and the
current [scene](#scenes) (`Demo 1` while a demo plays), with `*` once you have
changed something with the Aux knob since loading it. The bottom line is Layer
A's root note and scale, and the volume, or `[MUTE]`.

## First Run

On first power-up the screen shows **Not calibrated**. Choose **Setup** to
calibrate now, or **Skip** to do it later from **Menu > Tools > Full
Calibrate**. Until it is calibrated, some tracks may play once and then go
quiet.

To calibrate:

1. At **Clear platter**, remove all magnets and choose **OK**. The platter
   spins while the screen shows **Sampling...**, then stops.
2. At **Magnet at front**, place a single magnet on the start mark, on the
   outer track, then turn the platter by hand (or with the Speed knob) until
   the mark is in front of you. That spot is **Front**. Choose **OK**. Whichever way up the magnet sits
   becomes the normal side (Layer A).
3. **Calibrated!** means it worked. The start mark is now where each bar
   begins, and the table knows where Front is. The platter then turns the mark
   back to Front so you can take the magnet off. On an error, fix the magnet
   and choose **OK** again:
   - **No magnet found**: the magnet is not on the mark.
   - **Wrong track**: move it to the outer track.
   - **Too many magnets**: remove the extras.

Calibrate again after changing the sensor arm's height, since every reading
changes with it.

Each note plays when its magnet is centered on the sensor. The table works out
when that will be from how far the platter turns between first sensing a magnet
and its strongest reading. Each sensor learns that from the last few passes, so
after power-up timing settles within a few turns. **Menu > Tools > Sensor
Timing** shows what each sensor has learned.

### The start mark

The table keeps track of where the start mark is (StartPos), so external MIDI
gear starts its bars there. It remembers this when the table is turned off with
the platter stopped. If the power goes off while the platter is spinning, the
table shows **StartPos unknown** at power-up. Choose **Find** to set it again,
or **Skip** to use wherever the platter is now as the start (bars, scene loads
and Layer Turns then count from there). Turning the platter by hand while the table is off moves the mark
without the table knowing.

**Menu > Tools > Calib. StartPos** sets it again without a full calibration:

- **Auto**: place one magnet on the start mark, with nothing else on the outer
  track. Magnets on the other tracks can stay. Turn the platter by hand (or
  with the Speed knob) until the mark is in front of you, then choose **OK**. The platter spins until it
  has found the mark, sets Front, and turns the mark back to you. The motor
  lets go at this step so the platter turns freely, so choosing **Back** leaves
  StartPos unknown.
- **Manual**: first, at **Mark to front**, turn the Menu knob until the mark is
  in front of you, press, then choose **Yes** (**Skip** keeps the Front you set
  last time). Then, at **Mark to the arm**, turn it until the mark is under the
  arm, press, then choose **Yes**. **More** goes back to moving it.

Front does not change unless the table or your seat moves.

To check it, choose **Menu > Tools > Go to StartPos**. The platter turns until the
mark should be under the arm. **Menu > Tools > Go to Front** turns it to Front
instead, the shorter way round.

## Playing

Place magnets on the tracks and start the platter. Inner tracks are small and
fit 4 or 5 magnets per revolution; the outer tracks fit around 20, so put fast
parts on the outside.

Each magnet plays a different layer depending on which way up it sits:

- **Layer A**: the magnet the same way up as during calibration. Piano by
  default.
- **Layer B**: the magnet flipped over. Drums by default.

The magnets are colored on each side: **blue side up plays Layer A**, **black
side up plays Layer B**. This holds when calibration was done with the blue
side up; if your table plays them the other way round, swap them with
**Menu > System > Magnet Pole**. The [Record Designer](#record-designer) uses
the same colors.

Each layer has its own voice, key, octave, level, shift and direction, so one
set of magnets can play piano one way up and bass the other.

For single-voice play, set Layer B's Mode to **Same as A**. Both sides then play
the same, and it never matters which way up a magnet sits.

To play both layers from every magnet, set Layer B's Mode to **Stack**. Each
magnet then plays its Layer A note and its Layer B note together, whichever way
up it sits.

To have the layers take turns, set Layer B's **Layer Turns** to **Alternate**.
One revolution only the Layer A magnets play, the next only the Layer B
magnets, switching each time the start mark passes the arm. Which layer goes
first is not fixed. It works with any Mode: with Stack each turn plays both
layers' notes, with Same as A the flipped magnets play like Layer A on their
turn, and with Layer B Off every other revolution is a rest.

For other patterns, such as Layer B only every fourth revolution, or the
layers on cycles of different lengths, use [Edit Turns](#edit-turns).

### Placement Mode

**Menu > Tools > Placement Mode** turns the platter into a workbench for placing
magnets at [Front](#the-start-mark). The screen shows the step at Front, such as
`Step 5.0/16` (the start mark is step 1), and the eight tracks, 1 innermost.

| Knob | Turn | Press |
|---|---|---|
| Speed  | Moves the platter either way | Turns the mark to Front  |
| Aux | Moves to the next step either way | Moves to the next beat |
| Volume | Picks a track | Mutes or unmutes it |
| Menu | | Leaves Placement Mode |

Magnets play as they pass the arm, so muting the other tracks lets you hear one
track on its own. The mutes are cleared when you leave, and volume stays where
it was. Steps, beats and the readout need StartPos and Front; without them only
the Speed knob moves the platter.

## Main Menu

```
Sound Defaults   Layer A, Layer B
Play Setup       Beats/Rev, Pitch Step, Aux Fn, Scene Load, MIDI Fn, MIDI CC
Tools            calibration and maintenance
System           LCD Timeout, Menu Timeout, Welcome Tune, StartPos Check, Magnet Pole
Exit
```

Each setting is described under [Performance Functions](#performance-functions)
or [Setup Functions](#setup-functions). Choosing a value saves it.

**Sound Defaults** edits the Defaults scene (see [Scenes](#scenes)), and you
hear each change as you make it. If another scene is playing, it first asks
**Load Defaults?**. In these menus, a layer's name shows `(=A)` when Layer B is
on Same as A, and `(off)` when the layer is off, since its settings then have
no effect.

## Aux Knob

The Aux knob changes one function while the table plays, without leaving the
home screen.

- **Turn** from the home screen: the first click shows the current value, and
  each click after that changes it straight away.
- **Press** from the home screen: opens the function list at the top. Turn to
  pick a function, press to start changing it.
- While changing a function, press to go back: to the home screen if you got
  there by turning, otherwise to the list. In the lists, **Back** goes up a
  level. The Menu button returns straight to the home screen.

The function list:

| Entry | What it does |
|---|---|
| Pitch | Moves both layers together. |
| Layer A, Layer B | Open that layer's own functions: Voice, Voice Edit, Root Note, Scale, Edit Scale, Octave, Shift, Low Note, Wrap, Mode, Edit Turns, and Effects (Tone Cutoff, Delay Mix, Delay Feedback, Reverb Mix). See [Effects](#effects). |
| A/B Balance | Crossfades between the layers. See [Performance Functions](#performance-functions). |
| Layer Turns | Together, Alternate or Custom: whether the layers take turns by revolution. See [Playing](#playing) and [Edit Turns](#edit-turns). |
| Load Scene | Loads a scene at the next bar (or at once, with Scene Load on Now). See [Scenes](#scenes). |
| Save Scene | Saves the current sound as a [scene](#scenes). |
| Scene Codes | Get a short code for the current sound, or enter one. See [Scene Codes](#scene-codes). |
| Reset All | Undoes every Aux change. |
| Exit | Back to the home screen. |

**Aux changes are not saved.** They are for playing, on top of the current
scene. Power off, or choose **Reset All**, and the scene comes back as it was
saved. To keep the changes, save them as a scene.

The function the knob controls is saved, so it is still selected next time.
You can also set it from **Menu > Play Setup > Aux Fn**.

### Voice Edit

**Aux > Layer A > Voice Edit** (or Layer B) tweaks the voice that layer is
playing. Turn to pick a setting, press to change it, and each click is heard
from the next note:

| Setting | What it sets |
|---|---|
| Wave | Sine, Triangle, Saw or Square |
| Harmonics | The wave's harmonics, H1 to H16, each 0 to 100%. See below |
| Attack | How long the note takes to reach full volume, 0 to 2000 ms |
| Decay | How long it then takes to fall to the Sustain level, 0 to 2000 ms |
| Sustain | The level it holds while the note lasts, 0 to 100%. At 100% Decay does nothing |
| Release | How long it fades after the note ends, 0 to 3000 ms |
| Length | How long each note is held, 10 to 2000 ms |
| Filter | The voice's own filter and its envelope. See below |

A tweaked voice shows `*` in the Voice list, such as `Piano*`. Tweaks affect
only that layer. Like other Aux changes they are not saved, and choosing
another voice or loading a scene also drops them. **Save Scene** does not keep
them; use **Save As...** below. Drums and None cannot be edited.

#### Harmonics

**Harmonics** reshapes the wave by its harmonics, **H1** to **H16**, each with
a level from 0 to 100%. H1 is the note itself, H2 an octave above, and each
one after is a little higher again. The low ones change the character of the
sound the most; the high ones add brightness or buzz.

- The list starts with the levels of the current wave. The first change
  marks the edit: the list shows `Harmonics*` and Wave shows, for example,
  `Triangle*`. Saw and Square come out slightly duller once edited.
- Changing Wave drops the harmonic edits and plays the new wave as it is.
  Save the voice first to keep them.
- **Reset**, below H16, drops the edits and goes back to the stock wave,
  including the fuller Saw and Square.
- The overall volume stays the same however the levels are set. Only how
  loud each harmonic is compared to the others matters: all at 50% sounds the
  same as all at 100%.
- The steps widen as the level rises (0, 1, 2, 3, 5, 7, 10, 15, 20, 30, 40,
  50, 70, 100%), so each click is about the same change to the ear.

#### Filter

**Filter** gives the voice its own low-pass filter, which opens and closes
with each note, like the Attack to Release envelope does for volume but for
brightness. It is separate from the layer's Tone (see [Effects](#effects)).

| Setting | What it sets |
|---|---|
| Cutoff | How much of the top end gets through, 0 to 90%. 100% reads **Off**: no filter. |
| Resonance | A peak at the cutoff, 0 to 100%. |
| Amount | How far the envelope opens the filter above the cutoff, 0 to 100%. At 0% the filter stays at the cutoff (it is still on). |
| Attack, Decay, Sustain, Release | The filter's envelope, as for the volume above. |

A plucky sound: Cutoff low, Amount high, short Decay, low Sustain.

The filter never opens past about 14 kHz, however high Cutoff and Amount
go: above that the table's filter turns unstable and crackles.

To keep a tweaked voice, choose **Save As...** at the bottom of the Voice Edit
list:

- **Scene 3 Voice A** (the current scene, and the layer you are editing),
  first in the list: kept with this scene only, as its **Scene Voice**. The
  scene is set to play it straight away. Nothing else in the scene changes.
  Not offered in the Defaults scene or a demo.
- **Custom 1** to **Custom 8**: shared by every scene. The layer then plays
  it, and it appears in every Voice list. Saving over a used one asks first,
  and changes every scene that uses it.

Saving a scene to another slot copies its Scene Voice along.

### Edit Scale

**Edit Scale** sets the note each track plays: one note per track, instead of
a scale the tracks climb through. It sits under Scale in **Sound Defaults >
Layer A** (or Layer B), on the Menu knob, and in **Aux > Layer A > Edit
Scale**, on the Aux knob, to change it live.

The list shows the eight notes, slot 1 first, such as `1: C+0`. Slot 1 is the
inner track until Shift or Low Note moves it. The number after the note is its
octave from the layer's Octave, so `C+1` is the C above. Press a slot and turn
to move its note a semitone at a time, from one octave below to two above.
Until you change a note, the list shows the layer's current scale; the first
change turns it into **Custom**, starting from the same notes. A MIDI keyboard
can play notes in too: see Scale Learn, Fingered and One Finger under
[MIDI In](#midi-in).

The notes count from the root, so Root Note transposes them. Shift and Wrap
work as with any scale; with No Wrap, notes past slot 8 repeat an octave up.

**Reset**, below slot 8, undoes your changes: on the Aux it goes back to the
scale the current scene was saved with, and in Sound Defaults to the scale the
layer had when you opened Edit Scale. The list stays open.

Custom is saved with the scene like any other setting. To use it in other
scenes, choose **Save As** at the bottom of the list and pick **Custom 1** to
**Custom 8**. These appear in every Scale list. Choosing one copies its notes
into the layer, so changing a saved one later never changes a scene. Saving
over a used one asks first.

### Edit Turns

**Edit Turns** sets which revolutions a layer is heard on. It is in **Sound
Defaults > Layer A** (or Layer B), on the Menu knob, and in **Aux > Layer A >
Edit Turns**, on the Aux knob, to change it live.

The screen shows the layer's turns, one per revolution:

```
Turns: A    Back
>1 - - |
```

A number means the layer's magnets are heard on that turn, `-` that they are
not. `|` ends the cycle: after the last turn it starts again from turn 1. With
no `|` the cycle is 8 turns. Above, Layer A plays one revolution in three.

Turn the knob to move the cursor and press to change the turn under it: on,
off, then the end of the cycle (turn 1 cannot be the end), then on again.
Pressing the `|`, or a blank turn after it, makes the cycle 8 turns again; the
turns after the old end come back as they were. **Back** is past turn 8, on
the top line. Changes are heard at once.

Each layer has its own pattern, and the two cycles can be different lengths:
Layer A on `1--|` and Layer B on `1-|` gives three against two, repeating
every 6 revolutions. Turn 1 is the first revolution after the start mark
passes the arm. A magnet is heard by its own side's pattern: with Stack, a
normal magnet plays both layers' notes on Layer A's turns.

Changing a turn sets **Layer Turns** to **Custom**, starting from the pattern
it was playing (Alternate is `1-3-5-7-` for A and `-2-4-6-8` for B). Choosing
Together or Alternate again keeps the Custom patterns, so choosing Custom
brings them back. A layer with every turn off is silent, as with Mode Off.

## Scenes

A scene is the whole sound of the table: both layers (mode, voice, key, octave,
level, shift, wrap, low note, channel, effects), Layer Turns, Pitch and A/B Balance. The table always
plays one scene, shown on the home screen, with any Aux changes on top.

- **0: Defaults** is what **Sound Defaults** in the main menu edits. It is
  always there. Until you change it, it holds the factory sound.
- **1 to 8** change only when you save to them.

Using them:

- **Save Scene** (in the Aux function list): turn the Aux knob to pick a slot
  and press. The current sound, Aux changes included, goes into that slot.
  Saving over a used slot asks first.
- **Load Scene** (an Aux function): turn the Aux knob to step through the
  scenes. The one you land on loads at the start of the next bar, when the
  start mark passes the arm, so you can pick it any time and it lands on the
  downbeat. With the platter stopped it loads at once. To load scenes as soon
  as you pick them, set **Menu > Play Setup > Scene Load** to **Now**.

Each slot shows Layer A's root and scale, such as `2: D Minor`, or `3: (empty)`.

At power-up the table plays the last scene loaded or saved, without Aux changes.

**Demos** are scenes built into the firmware. They follow scene 8 in the Load
Scene list, as `Demo1: Drift` and so on, and load like any scene, power-up
and Aux **Reset All** included. They cannot be changed or lost: to keep changes
to one, save it to a slot. To make your own, or to copy your saved scenes off
the table, see [Scene Format](scene-format.md).

### Scene Codes

A scene code is a short code, up to 14 characters, for the sound you are
playing. Enter it on another table, or on this one later, to get the sound
back. Find it under **Scene Codes** in the Aux function list.

A code holds, for each layer: root, octave, scale, voice, shift, Low Note,
Wrap and mode, plus Layer B's Same as A settings and Layer Turns, with both
turn patterns when Layer Turns is Custom. Everything else (effects, level,
channel, Pitch, A/B Balance) loads as the factory sound. The more you have
changed, the longer the code: changing only the roots makes a 3-character
code. A code is at most 10 characters unless it uses Custom turns or one of
the voices from E. Piano on.

Codes hold the built-in voices and scales only. A Custom voice goes out as the
built-in it was made from, and a Learned or Custom scale as Major.

- **Get** shows the code for the current sound, Aux changes included.
- **Enter** builds a code one character at a time, on the bottom line. Turn
  the Aux knob to pick the character at the end of the code and press to take
  it. The characters run A to Z, then 2 to 9 (codes have no I, O, 0 or 1).
  Speed and Volume work as usual without leaving the screen. Past the characters are `<-` (press to delete the last one, or to leave
  when the code is empty) and a block (press when done); the top line says
  which, such as `Code: [<-=del]`. A 14-character code is checked as soon as
  it is complete. If the code is not a valid one, the screen says `Invalid
  Code`; press to go back and fix it. A valid code loads as soon as it is
  done, and the screen shows each layer's key and voice; press to close it.

A code loads like a scene, at the next bar or at once with Scene Load on Now.
It changes only the sound you are playing: the current scene stays, shown with
`*`, and nothing is saved. To keep it, save it as a scene.

Codes keep working after firmware updates.

### Record Designer

The [Record Designer](https://dmagoo.github.io/Magnetrone/tools/record-designer/) is a web page for
planning a record: a magnet pattern plus the Scene Code that sets the table up
to play it. Place magnets on a grid (Layer A or B, one row per track), set the
sound (including Layer Turns and each layer's turns), and listen to it in the
browser with the table's voices (forwards or backwards, or each layer's run
on its own, as the welcome tune plays it). Buttons swap the two layers' sound
settings, copy Layer A's to Layer B, or reset the scene. Songs can be saved in
the browser and shared as links. It shows the Scene Code to enter under
**Scene Codes > Enter**, and exports a full-size template (SVG or PDF) to print
and lay on the platter, or to laser cut into a cover with the magnet holes.
It also works offline: open `tools/record-designer/index.html` from a copy of
the project. Details are in its
[README](../tools/record-designer/README.md).

## Effects

Each layer has its own effects, which work on that layer's whole sound, in
this order: **Tone**, **Chorus**, **Delay**, **Reverb**. So Layer A can be a
wet, echoing piano while Layer B stays dry drums. Every effect is off in the
factory sound.

Set them in **Menu > Sound Defaults > Layer A > Effects** (and Layer B). There
is no On/Off: the setting that takes an effect out reads **Off** at its end of
the range. Values are in 10% steps.

| Effect | Settings | Off at |
|---|---|---|
| Tone | **Cutoff**, a low-pass filter that darkens the sound as it comes down; **Resonance**, a peak at the cutoff. | Cutoff 100% (Resonance then does nothing) |
| Chorus | **Rate** and **Depth** of the wobble, and **Mix**. Depth 0% is not off: a fixed delayed copy still colours the sound. | Mix 0% |
| Delay  | **Mode**, **Time**, **Feedback** (how many echoes, up to 90% so they always die out), **Mix**. | Mix 0% |
| Reverb | **Room Size**, **Damping** (how dark the tail is), **Mix**. | Mix 0% |

Delay **Mode**:

- **Sync**: Time is a fraction of one beat (see Beats/Rev): 1, 1/2, 3/8, 1/3,
  1/4, 1/5, 1/6, 3/16, 1/8, 1/10, 1/12, 1/16 or 1/32. The echoes follow the
  platter speed. The longest echo is 2.4 seconds; at slow speeds a longer
  time is halved until it fits, so the echoes stay in rhythm.
- **Free**: Time in milliseconds, 10 to 2400 ms.

Delay and Reverb keep running while their Mix is off, so turning Mix down
lets the echoes and tail fade out naturally rather than cutting them off.

On Layer B, each effect's list ends with **Same as A**: Yes plays Layer A's
settings for that effect. B's effects follow A's too while B's Mode is Same as
A. Either way the entries are tagged `(=A)`.

A drum layer goes through its effects too. The kit is shared, so when both
layers play drums, the drums go through Layer A's effects.

On the Aux (**Aux > Layer A > Effects**) you can change **Tone Cutoff**,
**Delay Mix**, **Delay Feedback** and **Reverb Mix** live. They also appear
under **Effects** in **Menu > Play Setup > Aux Fn**. With MIDI CC on, a MIDI
controller can change them too (see [MIDI In](#midi-in)).

## Performance Functions

Functions meant to be changed while playing. "Layer" means the setting is in
**Menu > Sound Defaults > Layer A** and **Layer B**, and each layer has its own.

| Function | Where  | Aux | What it does | Default |
|---|---|-----|---|---|
| Mode | Layer  | Yes | On or Off. Layer B also has Same as A: it plays exactly like Layer A. And Stack: every magnet plays both layers, whichever way up it sits. Off silences every magnet that way up. | On |
| Layer Turns | Layer B | Yes | Together: both layers play every revolution. Alternate: they take turns, one revolution each, so a magnet is only heard on its layer's turn. Custom: each layer plays its own pattern from Edit Turns. On the Aux it is in the main list, not under Layer B. See [Playing](#playing). | Together |
| Edit Turns  | Layer  | Yes | Which revolutions the layer is heard on, in a cycle of up to 8. See [Edit Turns](#edit-turns). | Every turn |
| Voice | Layer  | Yes | Piano, E. Piano, Organ, Synth, Bass, Strings, Brass, Mallets, Reed, Guitar, Drums or None, plus any saved Custom voices and, on the Aux, the scene's own Scene Voice. None silences the layer, handy for muting it live from the Aux. On Layer B, Same as A plays A's voice, Voice Edit tweaks included. | A: Piano, B: Drums |
| Root Note | Layer  | Yes | Key of the scale. On Layer B, Same as A follows A's root (picking a note sets B's own). Drums ignore it. | C; B: Same as A |
| Scale | Layer  | Yes | Major, Minor, Pentatonic Major and Minor, Blues, Chromatic, Dorian, Mixolydian, Learned (from an older MIDI Scale Learn, kept in scenes saved with it), Custom (one note per track, see [Edit Scale](#edit-scale), or played in from MIDI, see [MIDI In](#midi-in)), or a saved Custom 1 to 8. On Layer B, Same as A follows A's scale, its Custom and Learned notes included (picking a scale sets B's own). Drums ignore it. | Major; B: Same as A |
| Octave | Layer  | Yes | 0 to 7. On Layer B, Same as A follows A's octave. Drums ignore it. | A: 4; B: Same as A |
| Shift | Layer  | Yes | Moves the run up by scale degrees, 0 to 7. On Layer B, Same as A follows A's shift. On Drums it moves each drum to another track. | 0 |
| Wrap | Layer  | Yes | With Wrap, shifted notes past the top drop back to the bottom, so the run rotates across the arm. With No Wrap, the whole run moves up. If B follows A's shift, it uses A's Wrap. Drums always wrap. | No Wrap |
| Low Note | Layer  | Yes | Which end of the arm plays the lowest note: Inner or Outer. On Layer B, Same as A follows A. On Drums it flips the kit end to end. | Inner |
| Level | Layer  | No  | Layer volume, 0 to 100%. Also sets MIDI velocity. | 100% |
| Effects | Layer  | Some | Tone, Chorus, Delay and Reverb. See [Effects](#effects). | All off |
| Pitch | Aux only | Yes | Moves both layers together, root and octave as one, so turning up always raises the pitch. Step size is set by Pitch Step. Drums ignore it. | 0 |
| A/B Balance | Aux only | Yes | Crossfades between the layers. Centre is both at full level. | Centre |
| Load Scene  | Aux only | Yes | Loads a scene at the next bar, or at once with Scene Load on Now. See [Scenes](#scenes). | - |

When Layer B is on **Same as A**, the Aux knob shows **Layer B is Same as A**
instead of changing B's settings. Mode is the exception, so you can switch B
back from the Aux.

Layer B can also follow A one setting at a time: Voice, Octave, Root Note,
Scale, Shift (with its Wrap) and Low Note each have a **Same as A** choice.
Out of the box B's Octave, Root and Scale follow A, so changing Layer A's
key moves both layers. On the Aux, B's list for each starts with **Same as
A**: turn off it and B gets its own setting, starting from A's so nothing
jumps; turn back past the first value (or, on a list that goes round, past
either end) to follow A again. In **Sound Defaults > Layer B**, Same as A is
near the end of each list, and picking a value sets B's own. While B's Voice
follows A, Voice Edit on Layer B shows **B Voice is Same as A**; while its
Scale does, Edit Scale waits the same way.

Mode on the Aux is also the way to give a saved scene Stack: load the scene,
set Layer B's Mode to Stack on the Aux, then choose **Save Scene**.

## Setup Functions

Settings you choose once and leave alone, plus the Tools. "Layer" means the
same as above; the rest are under **Menu > Play Setup**, **Menu > System** and
**Menu > Tools**.

| Function | Where | What it does | Default |
|---|---|---|---|
| Channel | Layer | MIDI channel. Auto follows the voice (see [Voices and Drums](#voices-and-drums)), or pick 1 to 16. Saved in scenes. | Auto |
| MIDI In | Layer | The MIDI channel this layer listens on, or Off. Not part of scenes. | A: 1, B: 2 |
| Beats/Rev | Play Setup | Beats per revolution, 1 to 32. Sets the BPM shown and the MIDI clock, and the beats Placement Mode snaps to. | 8 |
| Pitch Step | Play Setup | How far one Aux click moves Pitch, from 1 semitone down to 1/8. Small steps give detuned, alien tunings. | 1 semitone |
| Aux Fn | Play Setup | Which function the Aux knob controls. | Layer A Voice |
| Scene Load | Play Setup | When a picked scene loads: Next Bar (on the downbeat) or Now. See [Scenes](#scenes). | Next Bar |
| MIDI Fn | Play Setup | What keys on an attached MIDI keyboard do. See [MIDI In](#midi-in). | Off |
| MIDI CC | Play Setup | On: MIDI controllers can change the effects. Off keeps settings you dialed in from changing unexpectedly. See [MIDI In](#midi-in). | Off |
| LCD Timeout  | System | How long the backlight stays on after you touch a knob, from Always Off to Always On. | Always On |
| Menu Timeout | System | How long a menu waits untouched before returning to the home screen: 5 s, 10 s, 30 s, 1 min or Never. | 30 s |
| Welcome Tune | System | Plays each track's Layer A note at power-up, quickly, in sixteenth notes. Press the Menu button to skip it. Turning it on plays it once as a preview. | On |
| StartPos Check | System | On: at power-up, offers to find the start mark if it was lost. Off: never asks. | On |
| Magnet Pole  | System | Swaps which way up is Layer A. Calibration sets it. | Set by calibration |
| Go to StartPos  | Tools | Turns the platter until the start mark is under the arm. See [The start mark](#the-start-mark). | - |
| Go to Front | Tools | Turns the platter the shorter way round until the start mark is in front of you (Front). See [The start mark](#the-start-mark). | - |
| Placement Mode  | Tools | The knobs move the platter by hand, by step or by beat, and mute tracks, for placing magnets. See [Placement Mode](#placement-mode). | - |
| Full Calibrate  | Tools | See [First Run](#first-run). | - |
| Reset Calib. | Tools | Clears calibration only, including the start mark. | - |
| Calib. StartPos | Tools | Sets the start mark again, Auto or Manual. See [The start mark](#the-start-mark). | - |
| Machine Info | Tools | Read-only pages, turned through with the Menu knob: RPM, belt ratio, StartPos (and where the platter is in the bar now), threshold, and whether the motor driver is answering. | - |
| Sensor Levels | Tools | Live reading of all 8 sensors, 1 to 4 on top and 5 to 8 below: which way each is pushed (+ or -) and by how much. Pass a magnet over a track to see its sensor respond. | - |
| Sensor Timing | Tools | One sensor per page, turned through with the Menu knob. Notes play when a magnet is centered on its sensor, and each sensor learns how far the platter turns from first sensing the magnet to its center. Top line: the sensor, how many of the last 8 passes it has learned from, **F** (how many of those had no clear center: a magnet too strong, too weak, or at the wrong height), and that angle. Bottom line: **Pk**, the last pass's strongest reading; **N**, the sensor's resting noise from calibration; **S**, how many readings the last pass lasted. Relearned every power-up, after a few turns. | - |
| Track Notes | Tools | What each track plays right now, Layer A on the top line and Layer B below, inner track on the left, two characters per track (`C D E F G A B C`). Includes everything that moves the notes: root, scale, octave, Pitch, Shift, Wrap and Low Note. Sharps or flats follow the key (D Minor shows Bb); Chromatic, Learned and Custom scales use sharps. Drums show a letter per drum: **X** crash, **t** low tom, **T** high tom, **C** clap, **O** open hat, **S** snare, **K** kick, **H** closed hat. Turn the Menu knob for more screens: each layer's key (`A: G Blues`), its Shift and Wrap (`A: Shift1 Wrap`; drums show `Kit`), and its Low Note (`A: Low Inner`). On Layer B, `=A` means it follows Layer A's setting (on the key screen, `B:=A C Major` when B follows A's root or scale). | - |
| Resources | Tools | How hard the sound engine is working, for checking there is headroom before adding voices or effects. Top line: **CPU**, the share of the processor the audio takes now, and its peak (**pk**). Bottom line: **Mem**, the sound buffers in use now and their peak, out of 160. Play something busy (both layers, many magnets, effects on) and read the peaks. Turn the Menu knob to reset the peaks. Speed and Volume work without leaving the screen. | - |
| Reset Settings  | Tools | Returns every setting to factory defaults, the Defaults scene included, keeping calibration, the start mark, scenes 1 to 8 and the saved voices and scales. Asks first. | - |
| Factory Reset | Tools | Erases everything, scenes, saved voices and scales, and calibration included. Asks first. | - |

## Voices and Drums

| Voice | Sound | MIDI channel (Auto) |
|---|---|---|
| Piano | Struck and fading, a bright click on the strike | 1 |
| E. Piano | Soft electric piano with a faint bell | 5 |
| Organ | Pipe organ, held | 6 |
| Synth | Hollow, pan-pipe-like synth | 4 |
| Bass | Saw bass with a short filter punch | 2 |
| Strings  | Slow, smooth swell | 3 |
| Brass | Horn with a brassy opening | 7 |
| Mallets  | Short struck bar | 8 |
| Reed | Clarinet-like, held | 9 |
| Guitar | Plucked, fading | 11 |
| Drums | Drum kit, one drum per track | 10 |
| None | Silent | - |

Synth was called Leads before 2026-10-06. Most voices are built from their
own harmonics (Voice Edit shows Harmonics\*), and most have their own filter
setting; Voice Edit starts from the voice's values.

Custom voices and Scene Voices (see [Voice Edit](#voice-edit)) use the MIDI
channel of the voice they were made from.

The drum kit, innermost track first:

| Track | 1 | 2 | 3 | 4 | 5 | 6 | 7 | 8 |
|---|---|---|---|---|---|---|---|---|
| Drum  | Crash | Low tom | High tom | Clap | Open hi-hat | Snare | Kick | Closed hi-hat |

The busiest drums sit on the outer tracks, which fit the most magnets. Shift
rotates the kit around the tracks, so any drum can be moved outward. A closed
hi-hat cuts off an open one, as on a real kit.

## MIDI

The Magnetrone sends on MIDI OUT:

- **Notes** on each layer's channel.
- **Clock** that follows the platter exactly, speed changes included, so drum
  machines and DAWs follow it.
- **Start**, **Stop** and **Continue** when the platter starts and stops. Once
  the start mark is set, starting also sends the position in the bar, so the
  external bars line up with the mark even when the platter starts mid-bar.
  Some gear ignores the position.
- **Pitch bend** for the Pitch function, so external synths follow detuned
  settings too.

### MIDI In

MIDI IN controls the table. Incoming notes play its sound only with the
**Play Along** MIDI Fn.

Each layer listens on its own channel (**Menu > Sound Defaults > Layer A >
MIDI In**, and the same for Layer B). A message on a
layer's channel applies to that layer, and with both layers on one channel it
applies to both. Pitch bend and volume respond on either layer's channel. Layer
B on Same as A does not listen, since it plays Layer A's settings.

- **Keys** drive the **MIDI Fn** (**Menu > Play Setup > MIDI Fn**), much as the
  Aux knob drives its function.
- **Pitch bend wheel** bends the whole table up to 2 semitones either way,
  notes already sounding included, and springs back.
- **CC 7** sets the volume. **CC 20** sets the octave. (A CC is the message a
  knob or slider on a controller sends; most controllers let you choose the
  number.)
- With **Menu > Play Setup > MIDI CC** on, these CCs change the
  [effects](#effects), each on the layer's channel:

  | CC | Sets |
  |----|------|
  | 74 | Tone Cutoff (the top of the knob is Off) |
  | 71 | Tone Resonance |
  | 93 | Chorus Mix |
  | 94 | Delay Mix |
  | 12 | Delay Feedback, 0 to 90% |
  | 91 | Reverb Mix |

  If Layer B's effect is on Same as A, B's CC for it does nothing.

| MIDI Fn | What the keys do |
|---|---|
| Off | Nothing. |
| Pitch | A key sets root and octave together: G3 makes the root G, octave 3. |
| Set Scale | Single-finger chords, as on arranger keyboards, but it sets a scale, not the chord's notes: middle C alone gives C major (C D E F G A B C), not C E G. For the chord's notes, use Fingered or One Finger. The highest key sets root and octave; extra keys to its left pick the scale: none = Major, a black key = Minor, a white key = Mixolydian (7th), both = Dorian (minor 7th). Keys pressed together count as one chord. |
| Fingered | The keys you hold are the scale, as **Custom**: low to high from the Low Note track, the lowest key setting root and octave. Fewer than eight repeat up by octaves (to two octaves up, then from the bottom again), so one held C plays C, C+1, C+2, C, C+1, C+2, C, C+1. Letting a key go removes it; lifting the whole hand keeps the last chord. Past eight keys, the extra ones are ignored. Drum layers ignore it. |
| One Finger  | Single-finger chords that play the chord's notes, like Fingered with the chord held: the same keys as Set Scale. The highest key is the root and sets the octave; alone it gives major (C E G), with a black key to its left minor (C Eb G), with a white key 7th (C E G Bb), with both minor 7th (C Eb G Bb). Middle C alone plays C E G C E G C E. Keys pressed together count as one chord, and it stays until the next. Drum layers ignore it. |
| Shift | A key sets which note the layer's low track plays. A key outside the scale picks the nearest scale note. Drum layers ignore it. |
| Play Along  | Keys play the layer's voice, like an ordinary keyboard, while the table keeps playing. Notes sound as played (Root Note, Octave and Scale don't apply), but Pitch and the bend wheel do, so the keys stay in tune with the table. Key velocity counts, scaled by the layer's Level and A/B Balance, and a note lasts as long as the key is held. With both layers on one channel, only Layer A plays. On a drum layer, each drum plays on its General MIDI key (36 kick, 38 snare, 42 closed hi-hat, 46 open hi-hat, 39 clap, 45 low tom, 50 high tom, 49 crash); other keys are silent. Keys share the layer's eight synth voices with the magnets; when all are busy, the oldest note stops. Keys are not sent to MIDI OUT. |
| Scale Learn | Each key goes in at the far end of the arm and every track's note slides one track toward the Low Note end; the note on the Low Note track drops off. Play eight keys and they lie low to high in the order played, repeats allowed. The first key turns the scale into **Custom**, starting from the scale already playing. The root stays on its track, so whatever slides onto it becomes the root (Root Note, and Octave if needed, follow without changing any note). This works at any Shift: it goes by the tracks you see. Drum layers ignore it. |

Like Aux changes, all of this is live and not saved, except the volume. Save a
scene to keep it. Scale Learn, Fingered and One Finger write the layer's
Custom scale, the one [Edit Scale](#edit-scale) edits: Save Scene keeps it, and
Edit Scale's **Save As** keeps it for other scenes. Keys are stored from the
layer's root and octave, so Root Note and Octave still transpose them; a key
out of the Custom range moves by octaves into it.

Not yet: following an external clock.

## Things to Try

Most of these are built in as [demos](#scenes), each changing only what the
idea needs: **Thirds**, **Key of G**, **Ladder** (double-length runs),
**Mirror**, **Chords** (Thirds with Stack), **Carousel** (Wrap on, for the
rotating melody) and **Turns** (two-revolution runs).

### With two layers

Set Layer B up the same as Layer A: Mode On (not Same as A), and the same
voice, root, scale and octave. Then change one thing on Layer B. A magnet plays
the layer of whichever side faces down, so a flipped magnet plays Layer B's
version of its note. Set Layer B's Mode to **Stack** instead and every magnet
plays both, so each idea below becomes a two-note chord.

- **Thirds.** Set B's Shift to 2. A flipped magnet plays a third above its
  Layer A note (Shift 4 gives a fifth, 5 a sixth). The intervals stay in the
  scale, so some thirds are major and some minor.
- **Another key.** Set B's Root a fifth above A's (C to G) or a third above (C
  to E). A flipped magnet plays exactly that interval higher. B is now in
  another key, so some notes clash with A.
- **Double-length runs.** Set B's Octave one above A's. The eight tracks now
  reach about two octaves: run a line up the tracks, then carry on up with
  flipped magnets.
- **Mirror.** Set B's Low Note to Outer. A flipped magnet plays the note from
  the other end of the arm.
- **Two-revolution runs.** Set B's Octave one above A's and its Layer Turns to
  Alternate. The challenge: an arpeggio that climbs the arm on one revolution
  with normal magnets, then carries on an octave higher on the next with
  flipped ones, two octaves over two revolutions.
- **Fills.** With [Edit Turns](#edit-turns), set Layer B to `---4|`: B's
  magnets play only every fourth revolution, a fill at the end of each
  four-bar phrase.

### With one layer

- **Backwards.** Turn Speed down past zero. The platter reverses and the
  pattern plays backwards.
- **Rotating melody.** Turn Wrap on, choose Shift on the Aux knob, and turn it
  while playing. The melody rotates across the arm.
- **Slow and dense.** Set a very low speed and Beats/Rev 16 or 32
  (**Menu > Play Setup > Beats/Rev**).

## Troubleshooting

**Noise or hiss from the speakers.** The audio board adds some noise of its
own. Turn the Magnetrone's volume up and your speakers down.

**Loud noise from the speakers when the Magnetrone is off.** Unplug the audio
cable whenever the Magnetrone is powered off.

**Motor doesn't turn, or moves erratically.** The motor needs the 24 V supply
plugged in and the power switch on. USB power alone is not enough.

**Power switch does nothing.** The unit is running from USB, which the switch
does not control. Use USB only for firmware updates and debugging, never to
power the unit, and do not connect it while the 24 V supply is plugged in.

**Display shows only black boxes.** The display was connected after the
Magnetrone was switched on. Switch it off and on again. Always connect the
display with the power off, and check the pin labels: a display lead plugged
in the wrong way round can damage it, and a damaged display can also silence
the sound.

**MIDI keys do odd things, or Scale Learn or Fingered pick up the wrong notes.** The other
device or DAW is probably echoing the table's MIDI OUT back to its input. Turn
off MIDI thru (echo) on that device.

**No sound, or the wrong layer plays.** Check **Menu > System > Magnet Pole**,
and check that the layer's Mode is On and its Voice is not None. If some tracks
play once and then stop, recalibrate.

**One track plays early or late.** Check that track in **Menu > Tools > Sensor
Timing**. A high **F** count or a low **Pk** means that magnet reads weakly or
unevenly: check that it is seated flat and that the sensor arm is level. Then
recalibrate.

### Diagnostics mode

A bench mode for tracking down hardware faults, used with a computer's serial
monitor over USB. Two ways in:

- Hold the Menu button while powering on.
- With the table running normally, type `diag` in the serial monitor. It
  restarts into diagnostics.

Type `exit` or power off to return to normal. In diagnostics the motor stays
off and nothing plays unless you ask. Every 5 seconds it beeps and prints a
report: whether the display and audio board answer, the motor driver's status,
and each sensor's reading, its resting level, the lowest and highest reading
since the last report, and how many times it fired. Faults print the moment
they happen. The display shows "DIAG" with a running time on the top line and
`0123456789ABCDEF` on the bottom; anything else on it means the display link is
faulty.

Commands (type `help` for the list):

| Command | Does |
|---|---|
| `spin <rpm>` | Runs the platter (negative for reverse) |
| `stop` | Stops the platter |
| `current <mA>` | Sets the motor current, up to 1700 |
| `chop stealth` / `chop spread` / `chop hybrid <rpm>` | Motor drive mode: quiet, strong, or quiet switching to strong above the given speed |
| `beep` | Plays the beep |
| `lcd` | Restarts the display |
| `hall <1-8>` | Streams one sensor's readings, 200 a second; press any key to stop |
| `exit` | Restarts normally |

Motor settings changed here are not saved.

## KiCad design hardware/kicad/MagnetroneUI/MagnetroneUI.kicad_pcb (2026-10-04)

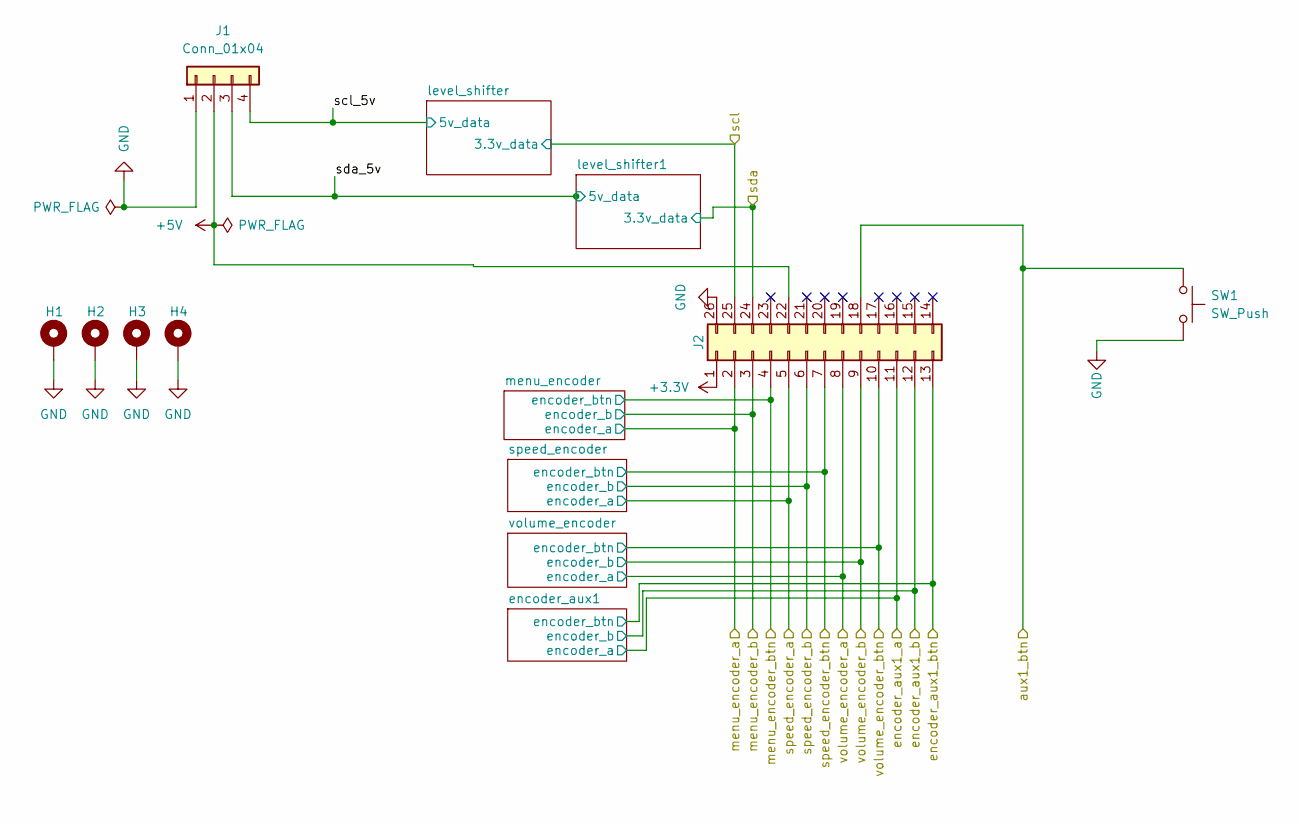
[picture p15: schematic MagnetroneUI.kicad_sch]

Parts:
H1, H2, H3, H4: MountingHole_Pad; MountingHole_3.2mm_M3_ISO7380_Pad_TopBottom
J1: Conn_01x04; PinHeader_1x04_P2.54mm_Vertical
J2: Conn_02x13_Counter_Clockwise; IDC-Header_2x13_P2.54mm_Horizontal
SW1: SW_Push; TerminalBlock_Phoenix_MKDS-1,5-2_1x02_P5.00mm_Horizontal

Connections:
+3.3V: J2.1; also elsewhere on the board
+5V: J1.2, J2.22; also elsewhere on the board
/aux1_btn: J2.18, SW1.1
/encoder_aux1_a: J2.11; also elsewhere on the board
/encoder_aux1_b: J2.12; also elsewhere on the board
/encoder_aux1_btn: J2.13; also elsewhere on the board
/menu_encoder_a: J2.2; also elsewhere on the board
/menu_encoder_b: J2.3; also elsewhere on the board
/menu_encoder_btn: J2.4; also elsewhere on the board
/scl: J2.25; also elsewhere on the board
/scl_5v: J1.4; also elsewhere on the board
/sda: J2.24; also elsewhere on the board
/sda_5v: J1.3; also elsewhere on the board
/speed_encoder_a: J2.5; also elsewhere on the board
/speed_encoder_b: J2.6; also elsewhere on the board
/speed_encoder_btn: J2.7; also elsewhere on the board
/volume_encoder_a: J2.8; also elsewhere on the board
/volume_encoder_b: J2.9; also elsewhere on the board
/volume_encoder_btn: J2.10; also elsewhere on the board
GND: H1.1, H2.1, H3.1, H4.1, J1.1, J2.26, SW1.2; also elsewhere on the board

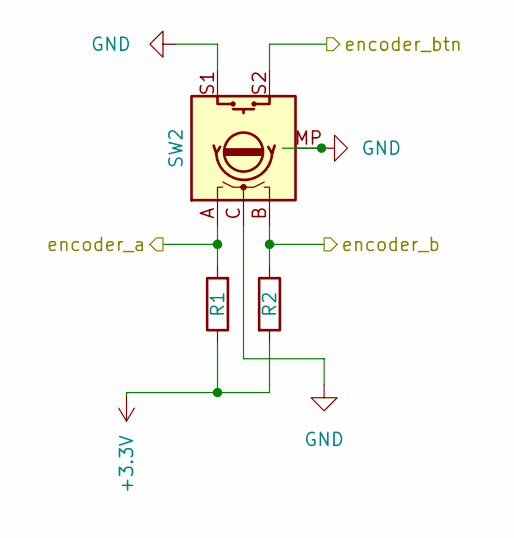
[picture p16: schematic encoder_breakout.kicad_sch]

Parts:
R1, R2: 10k; R_0805_2012Metric_Pad1.20x1.40mm_HandSolder
SW2: RotaryEncoder_Switch_MP; RotaryEncoder_Alps_EC11E-Switch_Vertical_H20mm

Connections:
+3.3V: R1.1, R2.2; also elsewhere on the board
/menu_encoder_a: R1.2, SW2.A; also elsewhere on the board
/menu_encoder_b: R2.1, SW2.B; also elsewhere on the board
/menu_encoder_btn: SW2.S2; also elsewhere on the board
GND: SW2.C, SW2.MP, SW2.S1; also elsewhere on the board

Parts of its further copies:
R3, R4, R5, R6, R7, R8: 10k; R_0805_2012Metric_Pad1.20x1.40mm_HandSolder
SW3, SW4, SW5: RotaryEncoder_Switch_MP; RotaryEncoder_Alps_EC11E-Switch_Vertical_H20mm

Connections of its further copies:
+3.3V: R3.1, R4.2, R5.1, R6.2, R7.1, R8.2; also elsewhere on the board
/encoder_aux1_a: R7.2, SW5.A; also elsewhere on the board
/encoder_aux1_b: R8.1, SW5.B; also elsewhere on the board
/encoder_aux1_btn: SW5.S2; also elsewhere on the board
/speed_encoder_a: R3.2, SW3.A; also elsewhere on the board
/speed_encoder_b: R4.1, SW3.B; also elsewhere on the board
/speed_encoder_btn: SW3.S2; also elsewhere on the board
/volume_encoder_a: R5.2, SW4.A; also elsewhere on the board
/volume_encoder_b: R6.1, SW4.B; also elsewhere on the board
/volume_encoder_btn: SW4.S2; also elsewhere on the board
GND: SW3.C, SW3.MP, SW3.S1, SW4.C, SW4.MP, SW4.S1, SW5.C, SW5.MP, SW5.S1; also elsewhere on the board

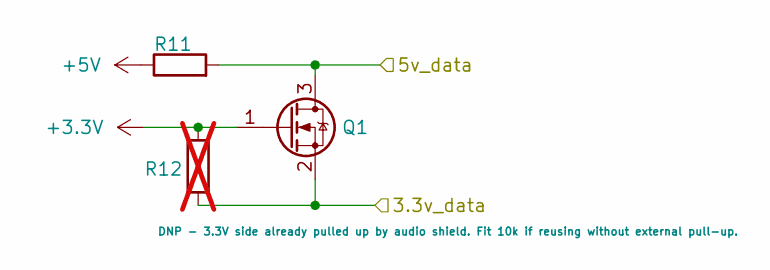
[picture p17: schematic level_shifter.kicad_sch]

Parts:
Q1: BSS138; SOT-23
R11: 10k; R_0805_2012Metric_Pad1.20x1.40mm_HandSolder
R12: 10k; R_0805_2012Metric_Pad1.20x1.40mm_HandSolder; not fitted

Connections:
+3.3V: Q1.1 (G), R12.1; also elsewhere on the board
+5V: R11.1; also elsewhere on the board
/scl: Q1.2 (S), R12.2; also elsewhere on the board
/scl_5v: Q1.3 (D), R11.2; also elsewhere on the board

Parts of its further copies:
Q2: BSS138; SOT-23
R13: 10k; R_0805_2012Metric_Pad1.20x1.40mm_HandSolder
R14: 10k; R_0805_2012Metric_Pad1.20x1.40mm_HandSolder; not fitted

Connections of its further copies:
+3.3V: Q2.1 (G), R14.1; also elsewhere on the board
+5V: R13.1; also elsewhere on the board
/sda: Q2.2 (S), R14.2; also elsewhere on the board
/sda_5v: Q2.3 (D), R13.2; also elsewhere on the board

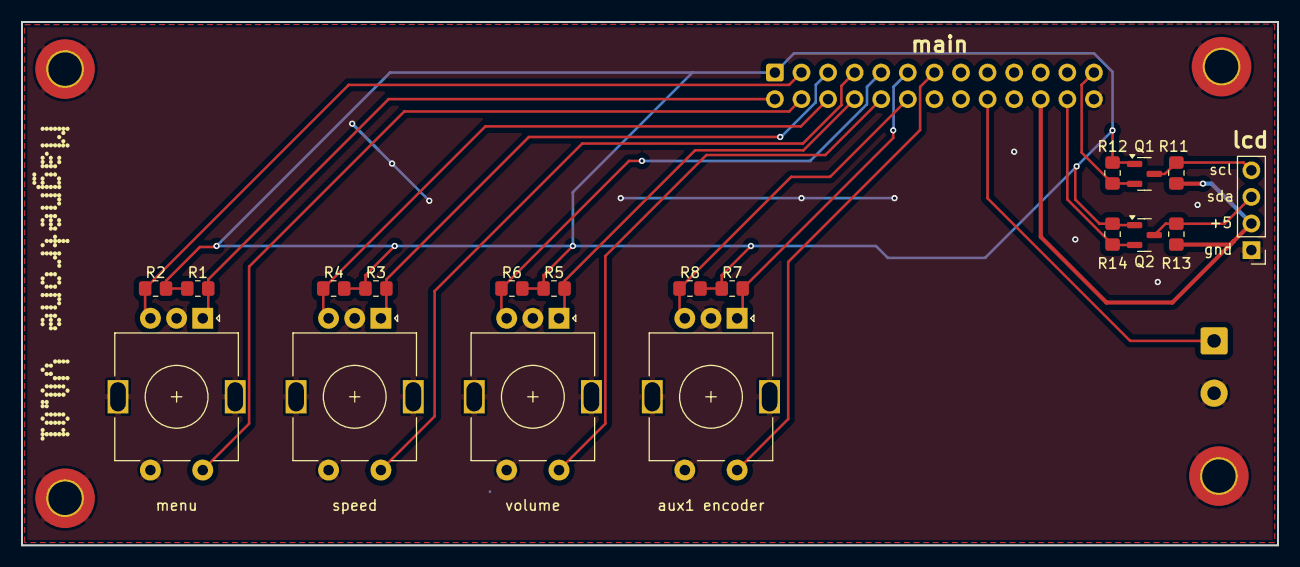
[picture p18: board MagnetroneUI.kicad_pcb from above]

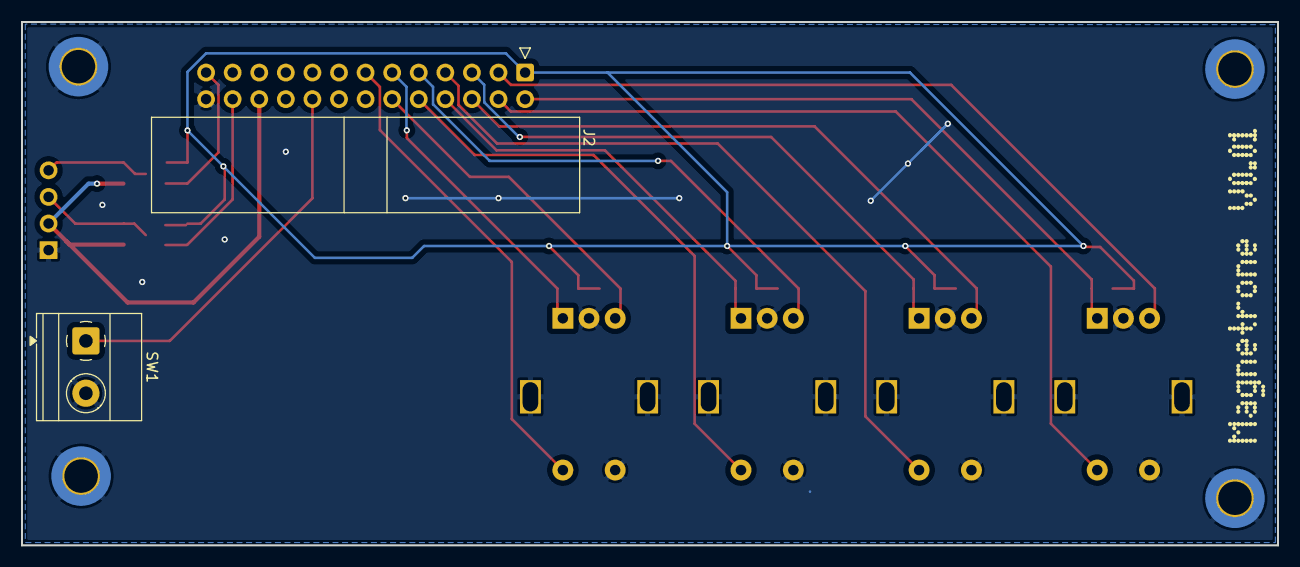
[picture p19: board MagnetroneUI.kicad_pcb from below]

Board: 2 copper layers, 120.0 x 50.0 mm, 25 parts (2 on the bottom side), 20 nets.

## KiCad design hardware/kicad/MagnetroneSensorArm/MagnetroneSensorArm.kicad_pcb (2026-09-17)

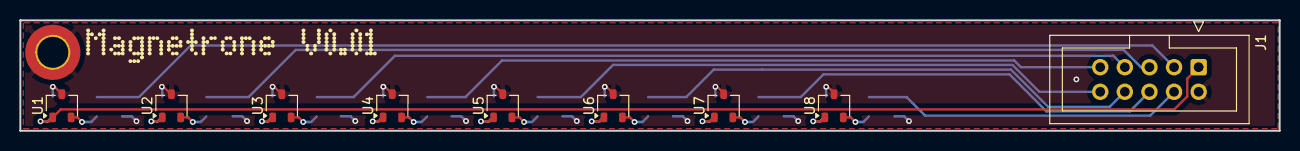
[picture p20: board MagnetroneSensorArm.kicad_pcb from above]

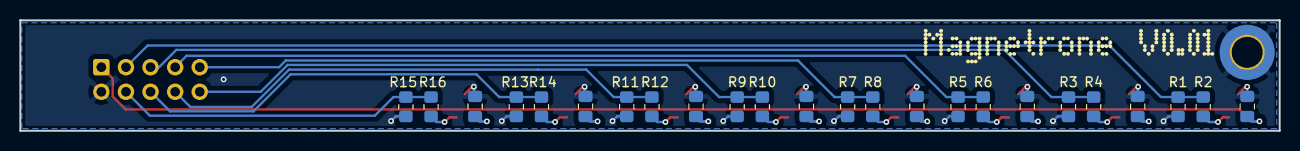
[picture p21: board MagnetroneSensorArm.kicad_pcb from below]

Board: 4 copper layers, 130.0 x 11.4 mm, 34 parts (24 on the bottom side), 18 nets.

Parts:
C1, C2, C3, C4, C5, C6, C7, C8: .1uf; C_0805_2012Metric_Pad1.18x1.45mm_HandSolder
H1: MountingHole_Pad; MountingHole_3.2mm_M3_ISO7380_Pad_TopBottom
J1: Conn_02x05_Odd_Even; IDC-Header_2x05_P2.54mm_Vertical
R1, R3, R5, R7, R9, R11, R13, R15: 15k; R_0805_2012Metric_Pad1.20x1.40mm_HandSolder
R2, R4, R6, R8, R10, R12, R14, R16: 7.5k; R_0805_2012Metric_Pad1.20x1.40mm_HandSolder
U1, U2, U3, U4, U5, U6, U7, U8: A1301KLHLT-T; SOT-23W

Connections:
+5V: C1.1, C2.1, C3.1, C4.1, C5.1, C6.1, C7.1, C8.1, J1.1, U1.1 (VCC), U2.1 (VCC), U3.1 (VCC), U4.1 (VCC), U5.1 (VCC), U6.1 (VCC), U7.1 (VCC), U8.1 (VCC)
/hall1: J1.3, R1.2, R2.2
/hall2: J1.5, R3.2, R4.2
/hall3: J1.7, R5.2, R6.2
/hall4: J1.9, R7.2, R8.2
/hall5: J1.10, R9.2, R10.2
/hall6: J1.8, R11.2, R12.2
/hall7: J1.6, R13.2, R14.2
/hall8: J1.4, R15.2, R16.2
GND: C1.2, C2.2, C3.2, C4.2, C5.2, C6.2, C7.2, C8.2, H1.1, J1.2, R1.1, R3.1, R5.1, R7.1, R9.1, R11.1, R13.1, R15.1, U1.3 (GND), U2.3 (GND), U3.3 (GND), U4.3 (GND), U5.3 (GND), U6.3 (GND), U7.3 (GND), U8.3 (GND)
unnamed: R2.1, U1.2 (VOUT)
unnamed: R4.1, U2.2 (VOUT)
unnamed: R6.1, U3.2 (VOUT)
unnamed: R8.1, U4.2 (VOUT)
unnamed: R10.1, U5.2 (VOUT)
unnamed: R12.1, U6.2 (VOUT)
unnamed: R14.1, U7.2 (VOUT)
unnamed: R16.1, U8.2 (VOUT)

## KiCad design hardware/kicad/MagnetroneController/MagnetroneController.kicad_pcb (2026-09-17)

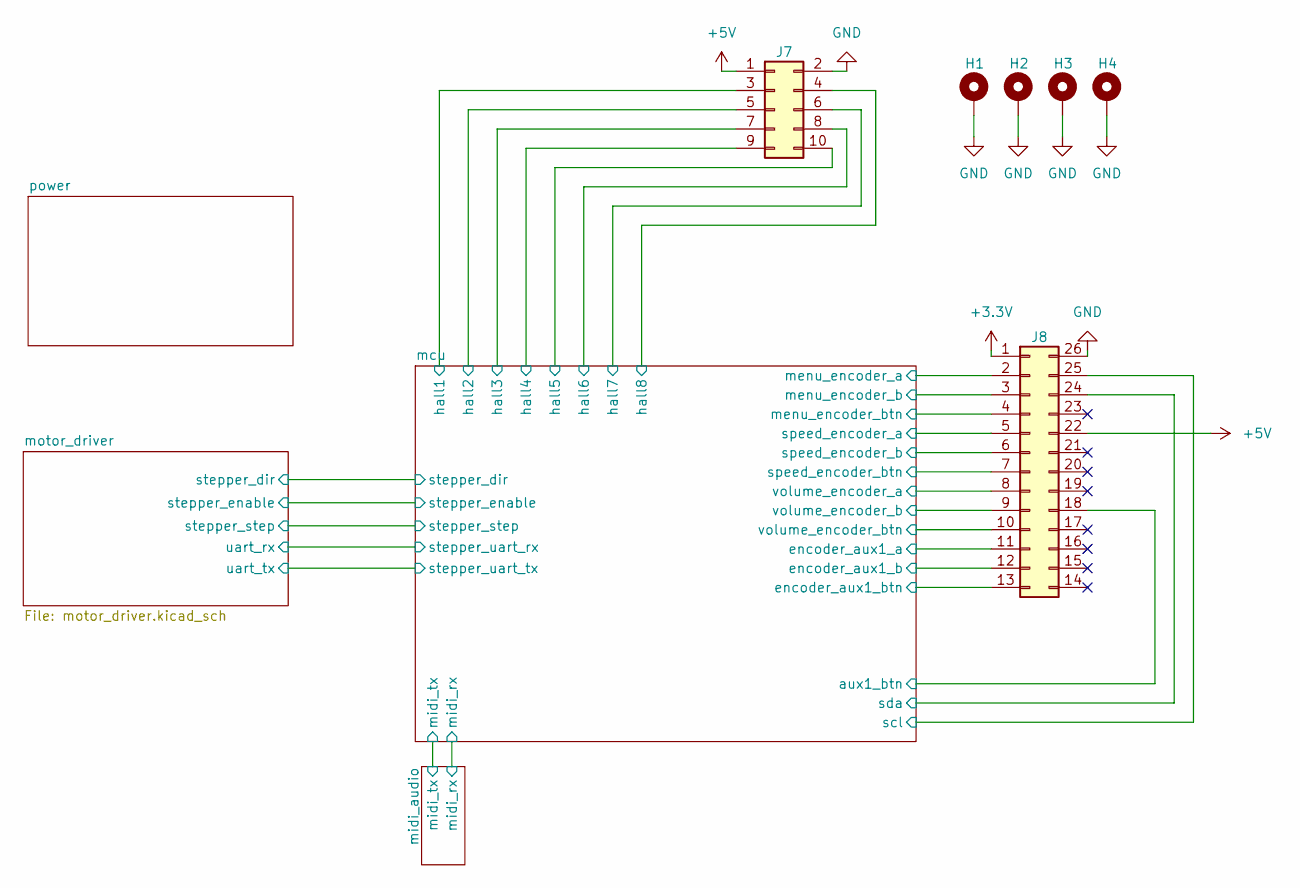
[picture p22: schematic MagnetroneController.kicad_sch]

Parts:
H1, H2, H3, H4: MountingHole_Pad; MountingHole_3.2mm_M3_ISO7380_Pad_TopBottom
J7: Conn_02x05_Odd_Even; IDC-Header_2x05_P2.54mm_Vertical
J8: Conn_02x13_Counter_Clockwise; IDC-Header_2x13_P2.54mm_Vertical

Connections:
+3.3V: J8.1; also elsewhere on the board
+5V: J7.1, J8.22; also elsewhere on the board
/mcu/aux1_btn: J8.18; also elsewhere on the board
/mcu/encoder_aux1_a: J8.11; also elsewhere on the board
/mcu/encoder_aux1_b: J8.12; also elsewhere on the board
/mcu/encoder_aux1_btn: J8.13; also elsewhere on the board
/mcu/hall1: J7.3; also elsewhere on the board
/mcu/hall2: J7.5; also elsewhere on the board
/mcu/hall3: J7.7; also elsewhere on the board
/mcu/hall4: J7.9; also elsewhere on the board
/mcu/hall5: J7.10; also elsewhere on the board
/mcu/hall6: J7.8; also elsewhere on the board
/mcu/hall7: J7.6; also elsewhere on the board
/mcu/hall8: J7.4; also elsewhere on the board
/mcu/menu_encoder_a: J8.2; also elsewhere on the board
/mcu/menu_encoder_b: J8.3; also elsewhere on the board
/mcu/menu_encoder_btn: J8.4; also elsewhere on the board
/mcu/scl: J8.25; also elsewhere on the board
/mcu/sda: J8.24; also elsewhere on the board
/mcu/speed_encoder_a: J8.5; also elsewhere on the board
/mcu/speed_encoder_b: J8.6; also elsewhere on the board
/mcu/speed_encoder_btn: J8.7; also elsewhere on the board
/mcu/volume_encoder_a: J8.8; also elsewhere on the board
/mcu/volume_encoder_b: J8.9; also elsewhere on the board
/mcu/volume_encoder_btn: J8.10; also elsewhere on the board
GND: H1.1, H2.1, H3.1, H4.1, J7.2, J8.26; also elsewhere on the board

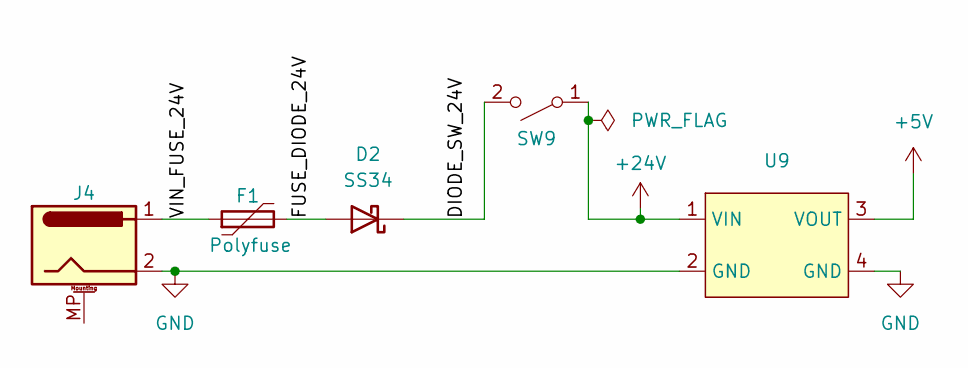
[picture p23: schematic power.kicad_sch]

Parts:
D2: SS34; D_SMA
F1: Polyfuse; Fuse_Bourns_MF-RHT300
J4: Barrel_Jack_MountingPin; BarrelJack_CUI_PJ-102AH_Horizontal
SW9: SW_SPST 24V; JST_XH_B2B-XH-AM_1x02_P2.50mm_Vertical
U9: SRT_MPT1584EN_Module

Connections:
+5V: U9.3 (VOUT); also elsewhere on the board
+24V: SW9.1 (A), U9.1 (VIN); also elsewhere on the board
/power/DIODE_SW_24V: D2.1 (K), SW9.2 (B)
/power/FUSE_DIODE_24V: D2.2 (A), F1.2
/power/VIN_FUSE_24V: F1.1, J4.1
GND: J4.2, U9.2 (GND), U9.4 (GND); also elsewhere on the board

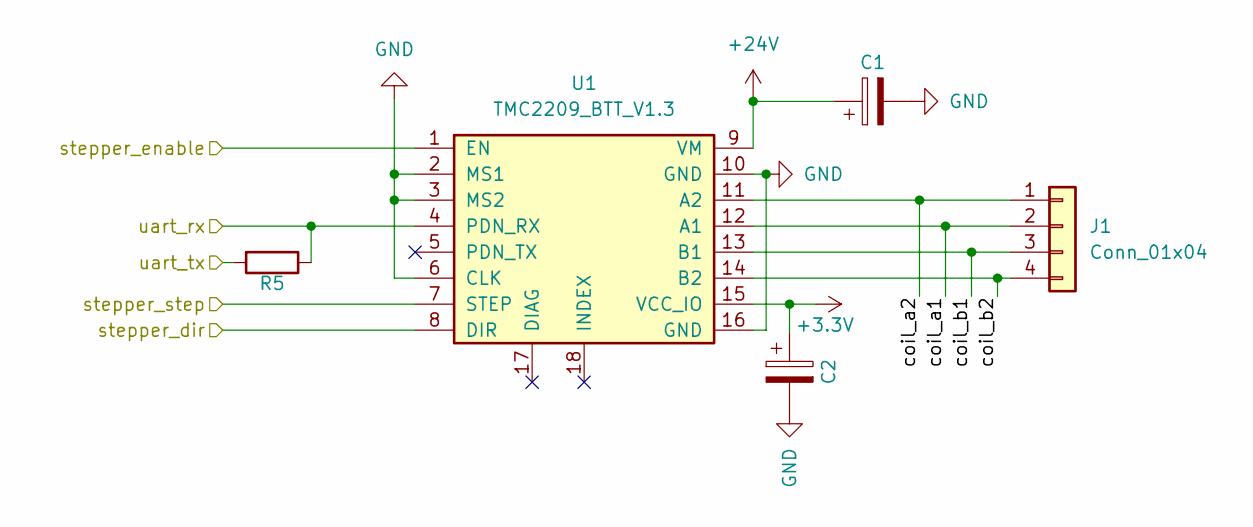
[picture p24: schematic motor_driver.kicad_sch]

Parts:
C1, C2: 100uf; CP_Radial_D8.0mm_P3.80mm
J1: Conn_01x04; PinHeader_1x04_P2.54mm_Vertical
R5: 1k; R_0805_2012Metric_Pad1.20x1.40mm_HandSolder
U1: TMC2209_BTT_V1.3

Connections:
+3.3V: C2.1, U1.15 (VCC_IO); also elsewhere on the board
+24V: C1.1, U1.9 (VM); also elsewhere on the board
/mcu/stepper_dir: U1.8 (DIR); also elsewhere on the board
/mcu/stepper_enable: U1.1 (EN); also elsewhere on the board
/mcu/stepper_step: U1.7 (STEP); also elsewhere on the board
/mcu/stepper_uart_rx: R5.1, U1.4 (PDN_RX); also elsewhere on the board
/mcu/stepper_uart_tx: R5.2; also elsewhere on the board
/motor_driver/coil_a1: J1.2, U1.12 (A1)
/motor_driver/coil_a2: J1.1, U1.11 (A2)
/motor_driver/coil_b1: J1.3, U1.13 (B1)
/motor_driver/coil_b2: J1.4, U1.14 (B2)
GND: C1.2, C2.2, U1.2 (MS1), U1.3 (MS2), U1.6 (CLK), U1.10 (GND), U1.16 (GND); also elsewhere on the board

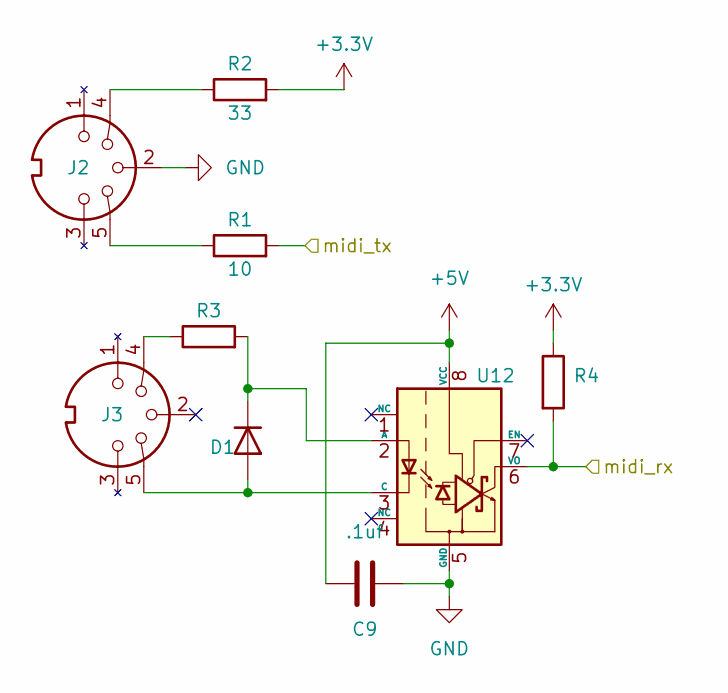
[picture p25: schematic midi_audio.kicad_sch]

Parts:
C9: .1uf; C_0805_2012Metric_Pad1.18x1.45mm_HandSolder
D1: D; D_SOD-123
J2, J3: DIN-5_180degree; MIDI_Wire_245
R1: 10; R_0805_2012Metric_Pad1.20x1.40mm_HandSolder
R2: 33; R_0805_2012Metric_Pad1.20x1.40mm_HandSolder
R3: 220; R_0805_2012Metric_Pad1.20x1.40mm_HandSolder
R4: 470; R_0805_2012Metric_Pad1.20x1.40mm_HandSolder
U12: 6N137; DIP-8_W7.62mm

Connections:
+3.3V: R2.2, R4.1; also elsewhere on the board
+5V: C9.2, U12.8 (VCC); also elsewhere on the board
/mcu/midi_rx: R4.2, U12.6 (VO); also elsewhere on the board
/mcu/midi_tx: R1.2; also elsewhere on the board
GND: C9.1, J2.2, U12.5 (GND); also elsewhere on the board
unnamed: D1.2 (A), J3.5, U12.3 (C)
unnamed: D1.1 (K), R3.2, U12.2 (A)
unnamed: J2.4, R2.1
unnamed: J2.5, R1.1
unnamed: J3.4, R3.1

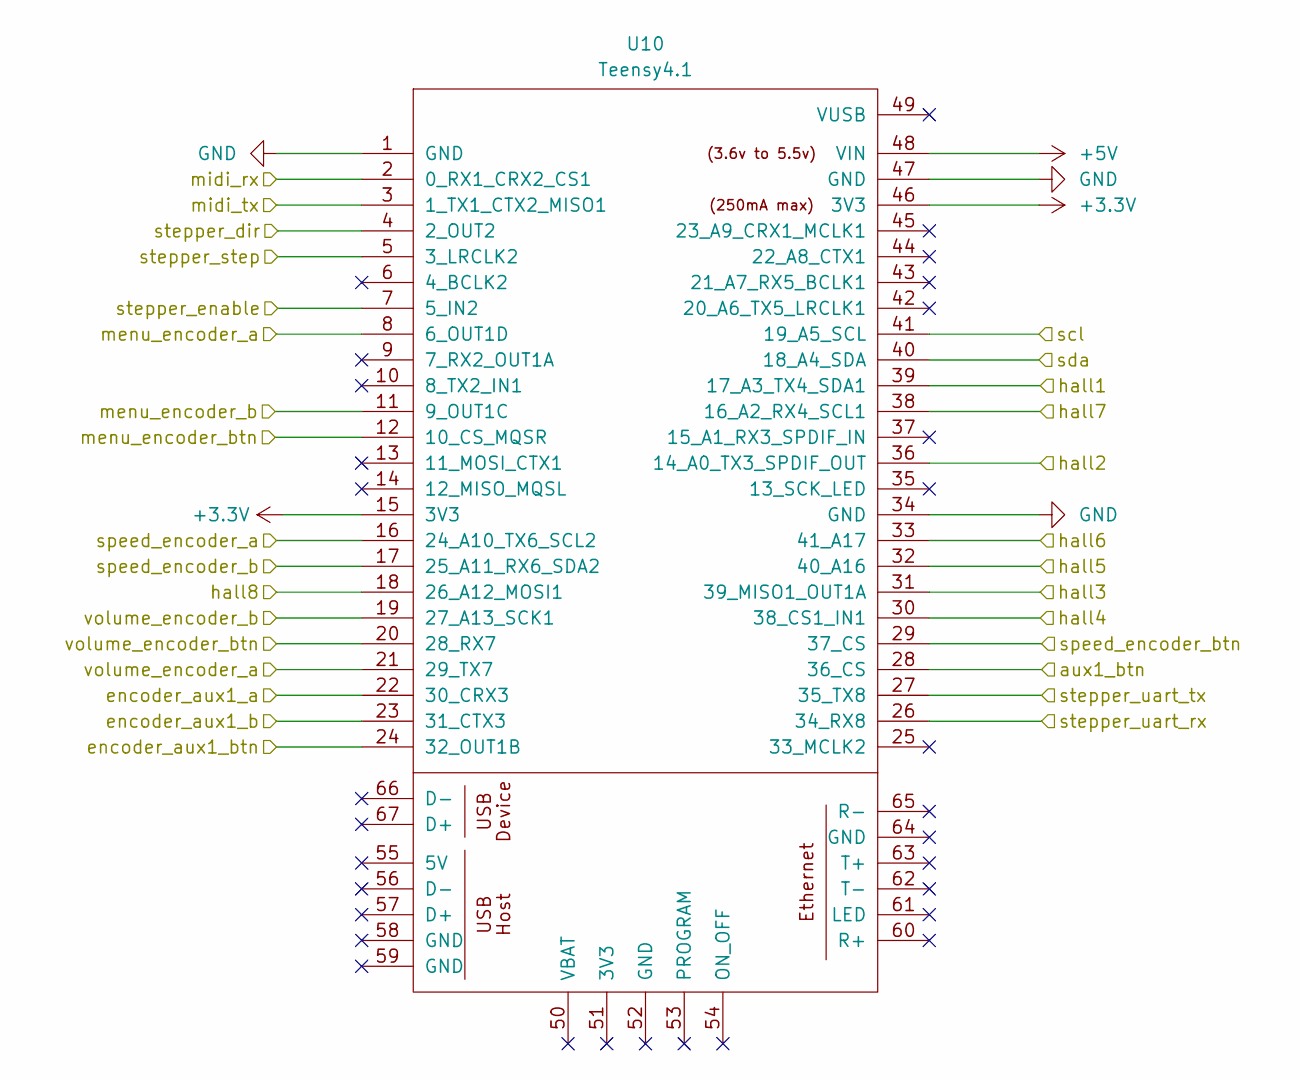
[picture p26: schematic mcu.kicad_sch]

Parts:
U10: Teensy4.1; Teensy41_AudioShield_RevD

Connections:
+3.3V: U10.15 (3V3), U10.46 (3V3); also elsewhere on the board
+5V: U10.48 (VIN); also elsewhere on the board
/mcu/aux1_btn: U10.28 (36_CS); also elsewhere on the board
/mcu/encoder_aux1_a: U10.22 (30_CRX3); also elsewhere on the board
/mcu/encoder_aux1_b: U10.23 (31_CTX3); also elsewhere on the board
/mcu/encoder_aux1_btn: U10.24 (32_OUT1B); also elsewhere on the board
/mcu/hall1: U10.39 (17_A3_TX4_SDA1); also elsewhere on the board
/mcu/hall2: U10.36 (14_A0_TX3_SPDIF_OUT); also elsewhere on the board
/mcu/hall3: U10.31 (39_MISO1_OUT1A); also elsewhere on the board
/mcu/hall4: U10.30 (38_CS1_IN1); also elsewhere on the board
/mcu/hall5: U10.32 (40_A16); also elsewhere on the board
/mcu/hall6: U10.33 (41_A17); also elsewhere on the board
/mcu/hall7: U10.38 (16_A2_RX4_SCL1); also elsewhere on the board
/mcu/hall8: U10.18 (26_A12_MOSI1); also elsewhere on the board
/mcu/menu_encoder_a: U10.8 (6_OUT1D); also elsewhere on the board
/mcu/menu_encoder_b: U10.11 (9_OUT1C); also elsewhere on the board
/mcu/menu_encoder_btn: U10.12 (10_CS_MQSR); also elsewhere on the board
/mcu/midi_rx: U10.2 (0_RX1_CRX2_CS1); also elsewhere on the board
/mcu/midi_tx: U10.3 (1_TX1_CTX2_MISO1); also elsewhere on the board
/mcu/scl: U10.41 (19_A5_SCL); also elsewhere on the board
/mcu/sda: U10.40 (18_A4_SDA); also elsewhere on the board
/mcu/speed_encoder_a: U10.16 (24_A10_TX6_SCL2); also elsewhere on the board
/mcu/speed_encoder_b: U10.17 (25_A11_RX6_SDA2); also elsewhere on the board
/mcu/speed_encoder_btn: U10.29 (37_CS); also elsewhere on the board
/mcu/stepper_dir: U10.4 (2_OUT2); also elsewhere on the board
/mcu/stepper_enable: U10.7 (5_IN2); also elsewhere on the board
/mcu/stepper_step: U10.5 (3_LRCLK2); also elsewhere on the board
/mcu/stepper_uart_rx: U10.26 (34_RX8); also elsewhere on the board
/mcu/stepper_uart_tx: U10.27 (35_TX8); also elsewhere on the board
/mcu/volume_encoder_a: U10.21 (29_TX7); also elsewhere on the board
/mcu/volume_encoder_b: U10.19 (27_A13_SCK1); also elsewhere on the board
/mcu/volume_encoder_btn: U10.20 (28_RX7); also elsewhere on the board
GND: U10.1 (GND), U10.34 (GND), U10.47 (GND); also elsewhere on the board


Board: 4 copper layers, 80.0 x 80.0 mm, 26 parts (0 on the bottom side), 46 nets.

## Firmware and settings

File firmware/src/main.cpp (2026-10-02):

#include <Arduino.h>
#include "config/storage.h"
#include "motion/stepper.h"
#include "ui/encoder.h"
#include "audio/audio.h"
#include "midi/midi.h"
#include "midi/transport.h"
#include "midi/midi_in.h"
#include "motion/bar.h"
#include "sensors/hall.h"
#include "menu/menu.h"
#include "sequencer/sequencer.h"
#include "sequencer/layers.h"
#include "sequencer/scenes.h"
#include "diag/diag.h"

static SavedConfig cfg;
static bool diagMode = false;

void setup() {
    diagMode = diagWanted();
    if (diagMode) { diagSetup(); return; }

    storageLoad(cfg);
    stepperInit();
    stepperSetCorrection(cfg.rpmCorrection);   // measured by calibration
    barInit(cfg);
    encoderInit();
    audioInit(cfg.volume, cfg.muted);
    midiInit();
    layersApply(cfg);
    hallInit();
    hallSetCalibration(cfg.hallBaseline, cfg.hallNoise, cfg.hallThreshold);
    hallSetPolarity(cfg.magnetPolarity);
    scenesInit(cfg);
    menuInit(cfg);
}

void loop() {
    if (diagMode) { diagLoop(); return; }

    stepperUpdate();
    encoderUpdate();
    hallUpdate();
    sequencerUpdate(cfg);
    menuUpdate(cfg);
    midiInUpdate(cfg);
    barUpdate(cfg);
    scenesUpdate(cfg);
    layersUpdate(cfg);   // Sync delay times follow the speed

    // Beat clock follows the platter's position, so it tracks the real speed.
    transportUpdate(cfg.beatsPerRev);

    diagPollSerial(cfg);   // "diag" and "scenes" in the serial monitor
}

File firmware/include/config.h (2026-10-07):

#pragma once
#include <stdint.h>
#include "sequencer/scale.h"

// -------------------------------------------------------------------------
// Audio
// -------------------------------------------------------------------------
constexpr float     DEFAULT_VOLUME       = 0.5f;    // 0.0 - 1.0
constexpr bool      DEFAULT_PLAY_WELCOME_TUNE = true;
constexpr uint8_t   LCD_I2C_ADDRESS      = 0x27;

// -------------------------------------------------------------------------
// Sequencer defaults
// -------------------------------------------------------------------------
constexpr RootNote  DEFAULT_ROOT         = RootNote::C;
constexpr Scale     DEFAULT_SCALE        = Scale::Major;
constexpr uint8_t   DEFAULT_OCTAVE       = 4;       // Layer A: middle C
constexpr uint8_t   DEFAULT_OCTAVE_B     = 3;       // Layer B: an octave below A
constexpr uint8_t   NUM_HALL_SENSORS     = 8;
constexpr uint8_t   DEFAULT_TRACK_SHIFT  = 0;   // per layer: scale degrees added to each sensor's degree
constexpr bool      DEFAULT_TRACK_WRAP   = false;  // per layer: No Wrap, the shifted run carries into the next octave
constexpr bool      DEFAULT_LOW_NOTE_OUTER = false;  // per layer: Low Note Inner, hall 1 plays the low end

// -------------------------------------------------------------------------
// Aux function knob
// -------------------------------------------------------------------------
// Which parameter the aux knob modulates. Index into the Fn list in menu.cpp.
// This binding is saved; the VALUES it modulates are live performance state and
// deliberately are not.
constexpr uint8_t   DEFAULT_AUX_FN       = 4;   // Layer A Voice (AuxFn::VoiceA)

// Pitch step size, stored as a divisor of one semitone: 1 = a half step,
// 2 = a quarter tone, and so on. Anything above 1 is microtonal -- exact on the
// internal synth, and carried over MIDI as a note number plus pitch bend.
constexpr uint8_t   DEFAULT_PITCH_STEP_DIV = 1;

// -------------------------------------------------------------------------
// MIDI in
// -------------------------------------------------------------------------
// Each layer listens on its own channel (0 = off). Most keyboards send on 1.
constexpr uint8_t   DEFAULT_MIDI_IN_CHANNEL_A = 1;
constexpr uint8_t   DEFAULT_MIDI_IN_CHANNEL_B = 2;
constexpr uint8_t   DEFAULT_MIDI_FN           = 0;    // Off
constexpr uint8_t   MIDI_CC_VOLUME            = 7;    // the standard volume CC
constexpr uint8_t   MIDI_CC_OCTAVE            = 20;   // no standard; unassigned
// Effects CCs, the General MIDI numbers. Only while Play Setup > MIDI CC is On.
constexpr bool      DEFAULT_MIDI_CC           = false;
constexpr bool      DEFAULT_SCENE_LOAD_NOW    = false;   // scene loads wait for the next bar
constexpr uint8_t   MIDI_CC_RESONANCE         = 71;
constexpr uint8_t   MIDI_CC_CUTOFF            = 74;
constexpr uint8_t   MIDI_CC_REVERB            = 91;
constexpr uint8_t   MIDI_CC_CHORUS            = 93;
constexpr uint8_t   MIDI_CC_DELAY             = 94;   // GM Effects 4 Depth; XG's variation send
constexpr uint8_t   MIDI_CC_DELAY_FEEDBACK    = 12;   // Effect Control 1, no fixed meaning
constexpr float     MIDI_BEND_IN_RANGE        = 2.0f; // semitones, the GM default

// -------------------------------------------------------------------------
// Hall sensors
// -------------------------------------------------------------------------
constexpr uint8_t   HALL_ADC_BITS           = 12;   // ADC resolution for hall sensors
// A1301 ratiometric sensor, 5V supply, voltage divider R1=3.3k/R2=6.8k -> Teensy 3.3V ADC
// Divider ratio: 6.8/10.1 = 0.673. Rest voltage: 2.5V * 0.673 = 1.68V -> ADC ~980 counts.
// Typical swing with magnet at operating distance: ~760-1200 counts.
// Default threshold: 200 counts deviation from baseline.
// Replaced by calibration measurement once calibration has run.
constexpr uint16_t  HALL_THRESHOLD_DEFAULT  = 200;

// Re-arm level: deviation must fall back BELOW this before a sensor that has
// fired is allowed to fire again. This is not simple hysteresis on the
// threshold -- it has to be close to baseline, because one magnet pass is not
// one clean bump. A disc magnet's return flux has the opposite sign to its face
// field, and hallUpdate() compares ABSOLUTE deviation, so a single pass can
// cross the threshold two or three times (fringe, face, fringe) and produce the
// double notes. Requiring a return to near-baseline means the dip
// between those lobes no longer re-arms the sensor.
//
// It replaces the old HALL_HYSTERESIS, which was subtracted from the threshold
// and went negative for any calibrated threshold below 100 -- that latched the
// sensor on permanently (flagged in the 2026-06-10 audit).
constexpr uint16_t  HALL_REARM_LEVEL        = 40;
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

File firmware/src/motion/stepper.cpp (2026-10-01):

#include "stepper.h"
#include "platter.h"

// Adapter layer. The app still talks to the free-function stepper API because
// menu.cpp and calibration.cpp are built around it; the implementation behind
// it is now the Platter class driving the TMC2209 over UART. Keeping the old
// surface meant those callers did not have to change.
//
// The previous A4988 implementation lived here directly: a bare IntervalTimer
// toggling PIN_STEP with no ramping. Platter adds soft start, slew-limited
// acceleration and the verified UART bring-up.

static Platter platter(Platter::defaultConfig());

// Platter::isStopped() is false before anything has been commanded, so asking
// it alone would report "running" at boot and turn the first knob press into a
// stop instead of a start. This tracks whether motion has ever been asked for.
static bool commanded = false;

// actual_rpm / commanded_rpm, as measured by calibration. Commanding
// rpm / correction makes the platter actually turn at rpm. 1.0 until
// calibration has run.
static float correction = 1.0f;

// True while the platter is being jogged by hand from the menu (Find Start).
// Cleared by any real start.
static bool jogging = false;

void stepperSetCorrection(float actualOverCommanded) {
    // Ignore absurd or uninitialised values rather than letting a bad EEPROM
    // read divide the commanded speed into nonsense.
    if (actualOverCommanded > 0.5f && actualOverCommanded < 2.0f) {
        correction = actualOverCommanded;
    }
}

void stepperInit() {
    platter.begin();
    // begin() energises the coils. Nothing has been commanded yet, so hold off
    // the holding torque (and its idle heat) until the first start.
    platter.disable();
}

void stepperUpdate() {
    platter.update();
}

void stepperStart(float rpm) {
    commanded = true;
    jogging   = false;
    platter.enable();
    platter.setRPM(rpm / correction);   // spins up from rest via pull-in + ramp
}

void stepperRelease() {
    platter.disable();
}

void stepperStop() {
    // Ramps to rest and keeps the coils energised so the platter holds
    // position rather than freewheeling. That is Platter's documented choice.
    platter.stop();
}

void stepperSetRPM(float rpm) {
    if (!commanded) return;   // matches the old API: no effect until started
    platter.setRPM(rpm / correction);
}

bool stepperRunning() {
    return commanded && !platter.isStopped();
}

float stepperCurrentRPM() {
    // Report the real platter speed, undoing the correction applied on the way in.
    return platter.currentRPM() * correction;
}

int32_t stepperPosition() {
    return platter.position();
}

uint32_t stepperStepsPerRev() {
    return platter.stepsPerPlatterRev();
}

void stepperJog(float rpm) {
    // Raw step rate: below MIN_RPM, which setRPM() would clamp away, and with
    // no correction, since nothing here is timed.
    commanded = true;
    jogging   = true;
    platter.enable();
    platter.setStepRate(rpm / 60.0f * (float)platter.stepsPerPlatterRev());
}

void stepperMoveBy(int32_t steps, float rpm) {
    commanded = true;
    jogging   = true;   // positioning, not playing
    platter.enable();
    platter.moveBy(steps, rpm);
}

uint8_t stepperDriverVersion() {
    return platter.driverVersion();
}

bool stepperJogging() {
    return jogging;
}

StepperDriverStatus stepperDriverStatus() {
    StepperDriverStatus s;
    s.version     = platter.driverVersion();
    s.gconf       = platter.driverGconf();
    s.gconfWanted = platter.driverGconfWanted();
    s.drvStatus   = platter.driverDrvStatus();
    s.gstat       = platter.driverGstat();
    return s;
}

void     stepperClearDriverGstat(uint8_t bits) { platter.driverClearGstat(bits); }
void     stepperSetCurrentMa(uint16_t ma)      { platter.setCurrentMa(ma); }
uint16_t stepperCurrentMa()                    { return platter.currentMa(); }

bool stepperSetChopper(bool spreadCycle, float hybridRpm) {
    return platter.setChopper(spreadCycle, hybridRpm);
}

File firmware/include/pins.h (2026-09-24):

#pragma once
// All pin numbers are GPIO numbers (Teensy 4.1 Arduino API).

// MIDI
constexpr int PIN_MIDI_RX       = 0;
constexpr int PIN_MIDI_TX       = 1;

// Stepper driver (TMC2209)
constexpr int PIN_DIR           = 2;
constexpr int PIN_DIR_TMP       = 6;    // used for testing as there was a broken teensy pin
constexpr int PIN_STEP          = 3;
constexpr int PIN_ENABLE        = 5;    // stepper_enable

// TMC2209 UART (Serial8)
constexpr int PIN_STEPPER_RX   = 34;
constexpr int PIN_STEPPER_TX   = 35;



// Menu encoder
constexpr int PIN_MENU_A        = 6;
constexpr int PIN_MENU_B        = 9;
constexpr int PIN_MENU_BTN      = 10;

// Speed encoder
constexpr int PIN_SPEED_A       = 24;
constexpr int PIN_SPEED_B       = 25;
constexpr int PIN_SPEED_BTN     = 37;  // press = stop/resume

// Volume encoderG
constexpr int PIN_VOL_A         = 29;
constexpr int PIN_VOL_B         = 27;
constexpr int PIN_VOL_BTN       = 28;  // press = mute/unmute

// Aux encoder 1 (reserved)
constexpr int PIN_AUX_ENC_A     = 30;
constexpr int PIN_AUX_ENC_B     = 31;
constexpr int PIN_AUX_ENC_BTN   = 32;

// Aux button (reserved)
constexpr int PIN_AUX_BTN_1     = 36;

// Hall effect sensors
constexpr int PIN_HALL_1        = 17;
constexpr int PIN_HALL_2        = 14;
constexpr int PIN_HALL_3        = 39;
constexpr int PIN_HALL_4        = 38;
constexpr int PIN_HALL_5        = 40;
constexpr int PIN_HALL_6        = 41;
constexpr int PIN_HALL_7        = 16;
constexpr int PIN_HALL_8        = 26;

// I2C - shared bus (LCD + audio shield SGTL5000)
constexpr int PIN_SDA           = 18;
constexpr int PIN_SCL           = 19;

// Audio shield I2S - managed by Teensy Audio Library, defined here for reference only.
// T4.1: MCLK=23, BCLK=21, LRCLK=20, DOUT=7, DIN(rx)=8
// Pins 7, 8, 20, 21, 23 are driven by the audio shield - do not connect or use.

// SD card SPI (reserved, not implemented)
// Pin 12: SPI MISO - do not use if external SD fitted

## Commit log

2026-06-05 initial import: music table kicad, firmware, notes
    [Music Table.kicad_pcb, Music Table.kicad_sch, PCBS.step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]
2026-06-06 feat: break into multiple boards
    [MagnetronController.kicad_pcb, MagnetronController.kicad_sch, MagnetronSensorArm.kicad_pcb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]
2026-06-07 chore: cleanup
    [MagnetronController.kicad_pcb, MagnetronUI.kicad_pcb]
2026-06-07 feat: cleanup
    [MagnetronSensorArm.kicad_pcb, MagnetronSensorArm.kicad_sch, MagnetronUI.kicad_pcb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]
2026-06-07 sensor step
    [MagnetronSensorArm.step]
2026-06-09 feat: updates
    [MagnetronController.kicad_pcb, MagnetronController.kicad_sch, MagnetronSensorArm.kicad_pcb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]
2026-06-09 feat: update to 2 layer board
    [MagnetronUI.kicad_pcb, MagnetronUI.kicad_sch]
2026-06-09 chore: cleanup/mounting holes
    [MagnetronUI.kicad_pcb, MagnetronUI.kicad_sch]
2026-06-13 chore: rename project files
    [MagetroneController-B_Cu.gbr, MagetroneController-B_Mask.gbr, MagetroneController-B_Paste.gbr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]
2026-06-15 chore: test for new motor driver
2026-06-15 chore: replace motor driver
    [MagnetroneController.kicad_pcb, MagnetroneController.kicad_sch, MagnetroneUI.kicad_pcb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]
2026-09-17 updates, and added tests
    [MagnetroneController-B_Cu.gbr, MagnetroneController-B_Mask.gbr, MagnetroneController-B_Paste.gbr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]
2026-09-23 feat: aux features, hall double-trigger fix, and calibration wiring
    Six backlog items plus two calibration UX fixes.
    Hall double-trigger: a magnet's return flux is opposite in sign to its face
    field and hallUpdate() compares absolute deviation, so one pass crossed the
    threshold two or three times. Sensors now re-arm only on a return to near
    baseline (HALL_REARM_LEVEL) rather than on falling back through the old
    HALL_HYSTERESIS band, which also removes a latch-on bug: that band went
    negative for any calibrated threshold below 100.
    Encoder buttons: 30 ms settle window, replacing the bare edge detect.
    MIDI: beat clock at 24 ppqn derived from platter BPM, with Start on first
    spin-up, Continue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
    [calibration.cpp, config.h, hall.cpp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]
2026-09-23 feat: aux function knob with live modulation and microtonal pitch
    The fourth encoder becomes a live modulation control. Three screens: the live
    display, an Fn select list, and a parameter screen. Turning the knob on the
    parameter screen applies each step immediately -- there is no press-to-confirm
    anywhere in the flow, which is what makes it modulation rather than menu
    navigation.
    The button is always "back", so the parameter screen records how it was
    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
2026-09-23 fix: keep aux knob modulation out of EEPROM
    The aux knob writes straight into the live SavedConfig, which is what the
    sequencer reads. That kept the read path simple but leaked: storageSave()
    writes the whole struct, so modulating the octave and then nudging the speed
    or volume knob persisted the modulation as a side effect.
    storage.cpp now keeps its own copy of what EEPROM holds. storageSave() writes
    everything except the aux-modulated fields, which keep their committed values,
    so any ordinary save is safe to call at any time regardless of what the knob is
    doing. storageCommit() is the menu's version, adopting the live values first --
    used only where the user deliberately set one of those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
    [menu.cpp]
2026-09-23 fix: aux encoder wakes the LCD backlight
    The backlight inactivity timer watched the menu, speed and volume encoders but
    not the aux one, so modulating with the aux knob let the light time out and
    left you adjusting in the dark.
    [menu.cpp]
2026-09-23 feat: aux parameter screen uses both lines for the value
    The Fn name took the top line and told you nothing you did not already know,
    having just bound the knob to it. Dropping it frees the line to show where the
    value sits relative to its neighbours, so on a list-shaped parameter the next
    value is visible before you turn into it.
    Pitch is continuous rather than a list, so it shows the offset in cents plus
    the step size currently in force.
2026-09-23 feat: Reset All on the aux Fn list
    Clears every live modulation at once -- the four aux-modulated config fields go
    back to their committed values and the pitch offset returns to zero -- then
    drops to the live display where the restored values are visible on the status
    line.
    Nothing is written to EEPROM. That drift never reached it, so reverting is
    purely a RAM operation. storageRevertLive() reuses copyLiveModulatedFields(),
    so the field list still exists in exactly one place.
    Reset is on the select list only, not on the menu that sets the default
    binding: that menu sets committed values, so there is nothing live to discard.
    [menu.cpp]
2026-09-23 fix: trigger on signed deviation, killing the double notes
    A disc magnet's field reverses sign at its edges, so one pass reads as fringe,
    face, fringe -- and the fringe lobes clear the threshold on their own. Comparing
    ABSOLUTE deviation made them indistinguishable from a real hit, so a single pass
    fired two or three notes. Worst on the slow inner tracks, where the lobes sit
    far enough apart in time to clear the debounce.
    The previous attempt at this raised the debounce and required a return to near
    baseline before re-arming. Neither could work: the signal genuinely passes
    through baseline between the lobes, which is exactly the condition the re-arm
    was watching for, and a slow pass outlast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
    [calibration.cpp, config.h, hall.cpp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]
2026-09-23 fix: per-sensor hall baselines, and a usable fresh-EEPROM state
    Two faults that both showed up as sensors behaving oddly rather than as
    anything obviously broken.
    Per-sensor baselines. The eight rest levels span roughly 150 counts and
    calibration averaged them into one number. An outlier then sits permanently
    further from that average than HALL_REARM_LEVEL, so it can never re-arm: it
    fires once and is silent for the rest of the session. Baselines are now
    measured and stored per sensor. The threshold stays shared because it is not
    measurable per sensor -- one magnet sits on one track, so calibration only ever
    sees a real hit on the single sensor that magnet passes.
    HALL_BASELINE_DEFAULT was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
    [calibration.cpp, config.h, hall.cpp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]
2026-09-23 feat: detect both magnet poles as separate triggers
    hallTrigger() replaces hallTriggered() and reports which pole fired,
    HallPole::Normal or HallPole::Reversed. Either sign now triggers.
    That is safe because the fringe lobes are far below the threshold:
    measured with test_hall_range on the hand-turned platter, they are
    5-9% of the face on all eight sensors. The sequencer still plays only
    Normal triggers, so nothing sounds different yet.
    test_hall_range now holds positive and negative peaks separately and
    shows the fringe-to-face ratio, since a single largest-magnitude peak
    hid the fringe.
    [hall.cpp, test_main.cpp]
2026-09-23 feat: voice presets with per-voice envelope and note length
    Four voices (Piano, Strings, Leads, Bass), each a waveform, ADSR
    envelope and note length, chosen from a new Voice menu entry. Note
    length moves from the global NOTE_DURATION_MS into the voice, since a
    slow Strings swell was cut off by the fixed 250 ms.
    EEPROM version 8 appends the voice field. A version 7 layout is a
    prefix of it, so storageLoad() migrates rather than wiping settings
    and calibration.
    [config.h, main.cpp, menu.cpp]
2026-09-23 feat: two magnet layers, so reversed magnets play their own voice
    Layer A plays the normal pole and Layer B the reversed one. Each has a
    mode, voice, MIDI channel (Auto follows the voice), octave offset and
    level. Layer B also has "Same as A", its default, so the table plays
    the same whichever way up a magnet sits.
    - Audio gets one 8-voice bank per layer; note off matches layer+note.
    - MIDI_CHANNEL is gone. Note on/off take a channel, and bend and bend
    range go to every channel in use.
    - The sequencer keeps note state per sensor per layer, and stores the
    channel with each note so a mid-note change still sends the matching
    Note Off.
    - Level rides on note velocity, so external synths fo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
    [config.h, main.cpp, menu.cpp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]
2026-09-23 feat: Drums voice, a shared GM kit either layer can play
    Drums is the fifth voice. It plays one fixed drum per track, busiest on
    the outer tracks: 1 crash, 2 low tom, 3 high tom, 4 clap, 5 open hat,
    6 snare, 7 kick, 8 closed hat, on GM note numbers (Auto channel 10).
    - Voices gain a note source, Scale or Kit. Drum handling keys on Kit,
    not on the Drums id, so further kits added as voices behave the same.
    - Drums skip the pitch offset (midiDrumOn), and kit layers are left out
    of the pitch bend channels. Root, scale and octaves are ignored.
    - Track Shift rotates the kit around the tracks, so a drum can be moved
    outward to fire more often.
    - Internal kit: SimpleDrum for kick, toms and sn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
    [menu.cpp, midi.cpp]
2026-09-23 feat: per-layer Track Shift with Wrap, and Low Note
    Track Shift moves from a master setting into each layer, with a Wrap
    setting, and a new per-layer Low Note (Inner / Outer) sets which end of
    the sensor arm plays the low end of the run.
    - Degree = (Outer ? 7 - i : i) + shift, wrapped modulo 8 with Wrap or on
    a kit. Shift up now raises the pitch whichever end is low; this
    reverses the old direction.
    - Layer B's shift (with Wrap) and Low Note each have their own Same as A
    binding, on by default, separate from the layer mode.
    - Aux Fns: Layer A/B Shift and Layer A/B Low replace Track Shift. The
    shift knob wraps under Wrap and clamps under No Wrap; Low Note clamps.
    A bound Layer B Fn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
    [config.h, menu.cpp, midi.cpp]
2026-09-23 feat: small UI pass, and fix recalibration undoing the speed correction
    - Menu button on the Aux screens returns to the live display.
    - The main menu's last entry reads "Exit"; submenus keep "Back".
    - Turning or pressing speed or volume returns to the live display from
    menus and Aux screens, never from a prompt. Menu or aux input in the
    same pass is dropped.
    - Turning the menu knob on the live display opens the main menu; the
    first detent is discarded.
    - A menu press cancels the welcome tune, at boot and in the menu
    preview. The sounding note is released, a following Setup/Skip prompt
    still shows, and the platter is serviced while the tune plays.
    - Calibration spins up with the cor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
    [calibration.cpp, menu.cpp]
2026-09-24 chore: GPL-3.0 license, rename hardware/stls to hardware/cad, doc cleanup
    - License changed from MIT to GPL-3.0
    - README: stepper driver is the TMC2209, not the A4988
    - Code comments no longer point at private notes
    - hardware/stls renamed to hardware/cad; KiCad STEP export paths follow
    - Remove stray Thumbs.db; gitignore it
    [MagnetroneController.step, MagnetroneSensorArm.step, MagnetroneUI.step]
2026-09-25 fix: main menu commits only the field it set, not all live Aux tweaks
    [menu.cpp]
2026-09-25 feat: bar start, calibration rework, Tools menu
    - Platter tracks a signed step position; bar start (StartPos) is the
    motor position where the start mark passes the arm. Phase saved at
    rest, invalidated on start (EEPROM v11); boot prompt when unknown,
    switchable via StartPos Check.
    - Full calibration split into Clear platter / Magnet on mark prompts,
    24 RPM, outer track only, belt ratio from step count, sets StartPos.
    - Calib. StartPos: Auto (magnet on mark) or Manual (jog). Go to StartPos
    moves the platter to the mark.
    - MIDI clock driven by platter position; Song Position Pointer +
    Continue on start when StartPos is known.
    - Main > Tools holds calibration and maintenance, plus I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
    [bar.cpp, calibration.cpp, config.h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]
2026-09-25 feat: scenes
    - 8 scene slots (EEPROM v12) holding everything Aux can change, pitch
    and A/B balance included.
    - Load Scene Aux Fn: steps through saved scenes, lands on the next bar
    start (immediately when stopped or StartPos is unknown).
    - Save Scene action in the Aux list; overwriting a used slot asks first.
    - Loading or saving makes the scene the saved setup; power-up plays it.
    Aux Reset All returns to it.
    - Live display drops RPM for "Scene N" plus "*" when modified; BPM is
    signed for reverse.
    [main.cpp, menu.cpp]
2026-09-25 feat: MIDI input (untested: no MIDI input device on hand)
    - Per-layer MIDI In channel (default A=1, B=2); shared settings accept
    either channel.
    - MIDI Fn (Main menu): Off, Pitch (key sets root + octave), Shift (key
    sets the low track's note, snapping to the scale), Scale Learn (seven
    keys make a live "Learned" scale, kept by scenes).
    - Pitch bend wheel: temporary +/-2 semitone offset.
    - CC 7 volume (saved after 2 s idle), CC 20 octave.
    - EEPROM v13.
    [config.h, main.cpp, menu.cpp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]
2026-09-25 feat: nested Aux list, Layer Octave Fn, Defaults scene, split resets
    - Aux list nests per-layer Fns under Layer A > / Layer B > (Voice,
    Octave, Shift, Low Note). Stored Fn numbers unchanged.
    - Layer Octave is an Aux Fn: live, reset by Reset All, kept in scenes
    (EEPROM v14; existing scenes take the layers' saved offsets).
    - Read-only "0: Defaults" scene first in Load Scene.
    - Tools Reset All split: Reset Settings keeps calibration, StartPos and
    scenes; Factory Reset erases everything.
    - User guide: MIDI In, nested Aux list, Defaults scene, resets.
    [menu.cpp]
2026-09-25 docs: call the live display the home screen; menu button is Home
2026-09-26 feat: Chord MIDI Fn (single-finger chords; untested)
    Highest key sets root and octave; extra keys to its left pick Major,
    Minor (black), Mixolydian (white) or Dorian (both). Keys within 40 ms
    count as one chord.
2026-09-26 fix: unmute restores the volume; volume changes while muted stay silent
    audioUnmute() was empty, so sound only returned on the next volume turn.
    The audio module now tracks volume and mute itself. Resets also restore
    the mute state.
    [menu.cpp]
2026-09-26 feat: Menu Timeout setting (5 s to Never, default 30 s)
    Replaces the fixed 5 s MENU_TIMEOUT_MS. EEPROM v15. Main menu entries
    are now named instead of numbered.
    [config.h, menu.cpp]
2026-09-26 feat: Aux press from the home screen opens the top of the Fn list
    Turning the knob on the home screen already reaches the current binding.
    [menu.cpp]
2026-09-26 hardware: add STL, DXF and 3MF files; move board STEPs to cad/pcb
    [Back Panel - Back Panel Stand.stl, Base Unit - LazySusanMount.stl, Frame - M5 Foot.stl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]
2026-09-29 feat: scene model rework, per-layer key, new menu layout
    Scene 0 is now Defaults, edited from Main > Sound Defaults (which first
    offers to load it if another scene is playing). Scenes 1-8 change only
    through Save Scene. Aux changes are live only, on top of the current
    scene; power-up plays the last scene without them.
    - Root, Scale and Octave move into each layer; the octave offset is gone.
    Scenes hold every layer setting, plus Pitch and A/B Balance.
    - Main menu: Sound Defaults, Play Setup, System, Tools, Exit.
    - Voice None mutes a layer.
    - Mode cues in the menus: "(=A)" and "(off)".
    - New defaults: Layer B plays Drums in octave 3, nothing bound to A;
    Wrap defaults to No Wrap; the Aux F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
    [config.h, menu.cpp]
2026-09-29 feat: Voice Edit, live tweaks to a layer's voice
    Aux > Layer A/B > Voice Edit tweaks the voice that layer plays: Wave
    (Sine, Triangle, Saw, Square), Attack, Decay, Sustain, Release and note
    Length, heard from the next note. Times step unevenly (0 ms to 3 s) so
    each click is audible; every preset's value is a step.
    Tweaks are per layer and live only: choosing another voice, loading a
    scene, Aux Reset All or a restart puts the stock voice back. A tweaked
    voice shows "*" in the Aux Voice list. Drums and None cannot be edited.
    [menu.cpp]
2026-09-29 feat: save edited voices to custom slots or the scene
    Voice Edit gets Save As: Custom 1-8, shared by all scenes, or the current scene's own voice for the layer. Voice lists show used customs and the Scene Voice. Save Scene copies a scene's own voice to the new slot. Reset Settings keeps saved voices. EEPROM v17, v16 migrated.
    [menu.cpp]
2026-09-29 feat: Voice Edit harmonics (H1-H16) with Reset; Aux button exits the main menu; user guide cleanup
    [menu.cpp]
2026-09-29 feat: platter minimum 1 RPM; Beats/Rev up to 32; user guide defines step
2026-09-29 feat: Front position (EEPROM v19), set first in calibration; Tools > Go to Front
2026-09-29 feat: Speed knob jogs at the Magnet at front prompts; README covers Front, Placement Mode and speed range
2026-09-29 feat: Layer B Mode Stack (every magnet plays both layers); Mode as a per-layer Aux Fn
2026-09-29 feat: per-layer effects (Tone, Chorus, Delay, Reverb), voice filter envelope, MIDI CC (EEPROM v20)
2026-09-29 fix: knobs ignore wiggles within a detent
    A click registers only after a full 4-count move from the last one. Dividing the raw count by 4 put the rounding edge on each detent, so a one-count wiggle read as a turn. Affects all four encoders.
2026-10-01 feat: diagnostics mode (serial reports, driver status, hall stats, motor tuning commands); docs
2026-10-01 feat: fire notes at the magnet's center (per-sensor learned timing), Sensor Timing page, calibration records noise (EEPROM v21)
    [calibration.cpp, config.h, diag.cpp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]
2026-10-01 docs: peak trigger, Sensor Timing, recalibrate after arm height change
2026-10-02 feat: demo scenes built from JSON (10 demos), scenes serial dump, Tools > Track Notes, Save As lists Scene Voice first, new factory defaults
2026-10-03 feat: Edit Scale Reset, back to the scale before editing (the saved scene on the Aux, the scale at entry in Sound Defaults)
    [menu.cpp]
2026-10-03 feat: custom scales (Edit Scale, Custom 1-8, EEPROM v23); Scene Load Next Bar/Now (EEPROM v24); StartPos Skip uses the current position; docs
    [config.h, menu.cpp, scene_dump.cpp]
2026-10-03 feat: Track Notes shift and low note screens
2026-10-03 fix: buffered LCD, only changed characters sent a few per loop, so menu redraws no longer stall note triggers; welcome screen drawn before the tune
    [menu.cpp]
2026-10-03 feat: Scene Codes, a short code for the live sound (Aux > Scene Codes: Get, Enter); docs
    [menu.cpp]
2026-10-04 Record Designer template fixes and docs (magnet colors, platter direction, hosted link); test sketches, fabrication outputs, scripts
    [MagnetroneController.csv, MagnetroneSensorArm.csv, MagnetroneUI.csv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]
2026-10-04 docs: Pages URL is case sensitive (Magnetrone)
2026-10-04 feat: Record Designer: reverse play, right click removes a magnet
2026-10-04 feat: Record Designer: theme toggle, magnet count, Shift options show the low track's note, Octave number box
2026-10-04 feat: Record Designer: Revert button, revert tooltip on the edited chip
2026-10-04 fix: Record Designer: resume iOS interrupted audio, pause and reset audio when the page is hidden
2026-10-05 feat: MIDI In: Scale Learn enters a Custom scale track by track, new Fingered MIDI Fn
2026-10-06 feat: Layer Turns Custom: per-layer turn patterns, Edit Turns, Scene Code v2; Record Designer Reset Scene
    [bar.cpp, menu.cpp, scene_dump.cpp]
2026-10-06 fix: Scene Code entry: A-Z 2-9 picker order, valid code loads at once, Speed/Volume keep the entry screen
    [menu.cpp]
2026-10-07 fix: voice filter: 14 kHz ceiling (SVF unstable above) and 6 dB headroom (clipping inside it); Record Designer matches
2026-10-09 feat: Record Designer: sticky track label column on the Sequencer grid
2026-10-09 fix: Record Designer: playback follows Edit Turns past turn 2; shade the current turn
2026-10-13 feat: Record Designer: scroll to active song chip, dark B magnets match the table with A/B letters, reverse icon, Scene Code moved to the Scene header, collide tooltip
2026-10-13 feat: Record Designer: Layer A/B buttons with Shift-click for the other layer, Same as A shows what plays and unlinks on edit, drum legend, folding Edit Scale/Edit Turns, Reset Scene beside Load
2026-10-13 fix: Record Designer v2: turned grid fills the width, drums legend and layer buttons in a row under the grid
2026-10-14 feat: Record Designer v2: Place row above the grid with magnet buttons, Drum key on demand, Apply to on the scene bar
